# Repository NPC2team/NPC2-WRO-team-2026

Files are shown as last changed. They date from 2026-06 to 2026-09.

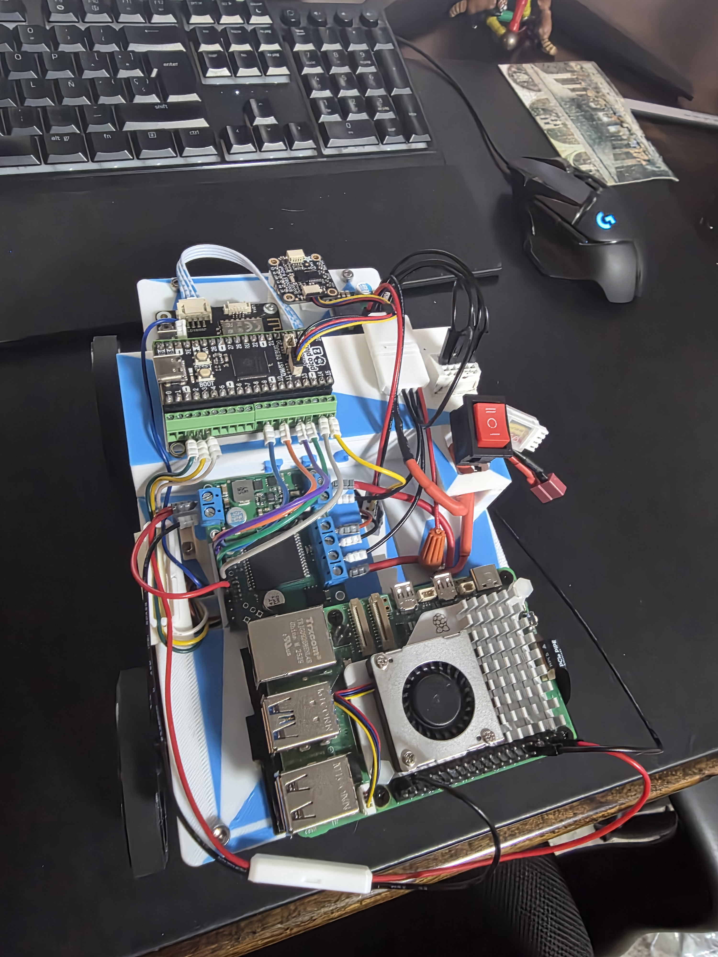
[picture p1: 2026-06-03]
setup of the car and software/Carro desde Arriba Listo.jpg

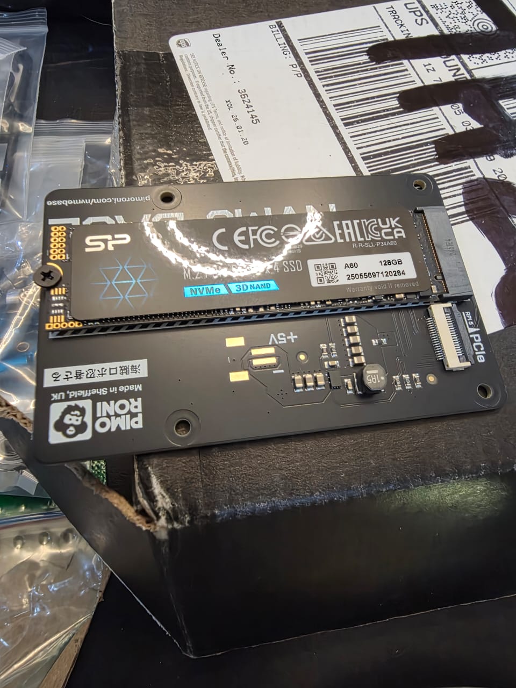
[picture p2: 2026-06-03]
setup of the car and software/Base NVME.jpeg

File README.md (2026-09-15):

## **NPC – WRO FUTUROS INGENIEROS 2026** 

## **CONTENIDO** 
## **1. Introducción e Información del Equipo**
- a. Introducción 
- b. Miembros del Equipo 
## **2. Vehículo** 
- a. Descripción del Vehículo 
- b. Fotos del Vehículo 
## **3. Videos de Pruebas del Vehículo** 
- a. Reto 1 – Open Challenge 
- b. Reto 2 – Obstacle Challenge 
## **4. Movilidad y Diseño Mecánico (Criterio 1)** 
- a. Chasis 
- b. Sistema de Tracción 
- c. Sistema de Dirección 
## **5. Arquitectura de Potencia y Sensores (Criterio 2)** 
- a. Sistema de Potencia 
- b. Power Budget 
- c. Sensores 
- d. Diagrama de Comunicación 
- e. Ubicación de Sensores 
- f. Diagrama de Cableado 
- g. Decisión de Diseño
## **6. Arquitectura de Software y Estrategia de Obstáculos  (Criterio 3)** 
- a. Visión General
- b  Estructura del Código
- c. Tópicos 
- d. Firmware del Pico 2 
- e. Estrategia del Reto Abierto
- f. Diagrama de Flujo de Reto Abierto
- g. Métricas de Desempeño del Reto Abierto 
- h. Nodos y Tópicos de Reto con Obstáculos
- i. Estrategia del Reto con Obstáculos
- j. Detección de Pilares R/G/M (cámara)
- k. Diagrama de Flujo de Reto con Obstáculo
- l. Métricas de Desempeño del Reto con Obstáculos
- m. Ajustes Realizados en Ambos Retos
## **7. Pensamiento Sistémico y Decisiones de Ingeniería (Criterio 4)** 
 - a. Diagrama de Bloques del Sistema
 - b. Interacción entre Subsistemas
 - c. Restricciones (Constraints) Identificadas
 - d. Decisiones de Diseño Principales
 - e. Análisis de Riesgos y Mitigación
 - f. Historial de Iteraciones (resumen)
## **8. Instrucciones de Reproducibilidad (Criterio 5)** 
 - a. Requisitos de Hardware
 - b. Requisitos de Software
 - c. Instalación Paso a Paso
 - d. Estructura del Repositorio
 - e. Cómo Arrancar el Sistema
 - f. Notas de Ensamblaje
 - g. Journal Detallado
<br>
<br>

## **1. Encabezado e Información del Equipo** 

## 1a. Introducción 
<div>
Equipo<br>
   
Somos el equipo **NPC (Non Playable Character)**, este es nuestro segundo año en competencias de la WRO, con el objetivo de lograr un vehículo verdaderamente autónomo que supere con éxito los retos de la competencia WRO Futuros Ingenieros 2026 a Nivel Nacional y nos permita obtener nuestro cupo en la Final Internacional de Puerto Rico. 

Vu Tue Anh, compitió el año pasado en la categoría de Misiones Roboticas, mientras que Leonardo y Juan participaron en la categoría de Futuros Ingenieros, llegando a la Final Nacional de Venezuela donde obtuvimos el 5to Lugar, mientras que en un invitacional en Weifang, China logramos el 1er Lugar. 
</div>
<br clear="left" />

## 1b. Miembros del Equipo 

## **Juan Ignacio Gonzalez** 

foto de juan<br>
Hola soy Juan, soy venezolano/español y tengo 16 años, actualmente estudio 4to año de bachillerato y miembro del Club de Robótica del Colegio Jefferson.  Este es mi segundo año en la competencia de la WRO de Futuros Ingenieros. En 2025, junto con Leonardo obtuvimos el 5to Lugar en la Final Nacional y el 1er Lugar en un invitacional en Weifang, China. 

Mis aportes al equipo se han enfocado en el código de Arduino IDE/Python, así como la realización de pruebas de los distintos componentes y de los retos. 

<br clear="left" />

## **Leonardo Carrasquero** 

Foto Leo<br>
Hola soy Leo, venezolano/italiano de 16 años, estudio 4to año de bachillerato y soy miembro del Club de Robótica del Colegio Jefferson 2024.  Al igual que Juan, este es mi segundo año en la categoría de Futuros Ingenieros y este año quiero lograr participar en la Final Internacional de Puerto Rico. 

Mis contribuciones se enfocaron en la investigación de componentes, diseño e impresión de piezas 3D, ensamblaje del robot, así como programación en Python y ROS2. 

<br clear="left" />

## **Vu Tue Anh** 

Foto Vu<br>
Hola soy Vu, de origen vietnamita y llevó 3 años viviendo en Venezuela y soy compañera de 4to año de Juan y Leonardo, en el Colegio Jefferson. Este también es mi segundo año en competencias de la WRO, pero el año pasado estuve en la categoría de misiones roboticas. Este año quise cambiar y tener el reto de participar en Futuros Ingenieros. 

Para nuestro proyecto, fui responsable en la realización de pruebas, así como de la documentación y registro fotográfico. 

<br clear="left" />

## **Alfredo Gonzalez**

<br>
Alfredo, es nuestro coach y de profesion matemático. 

Él también es nuestro profesor de robótica en el Colegio Jefferson y ha estado desde 2023 participando en competencias de la WRO en Venezuela, dirigiendo a varios equipos del colegio en las distintas categorias, con participaciones en las Regionales, Final en Venezuela, Final Internacional y diversos invitacionales.

<br clear="left" />

## **Foto del Equipo Junto y Foto en China** 

Foto Equipo China

3DC51F0D-4A7F-49F5-A332-7C0CE98BB8BD

## **2.Robot** 

## 2a. Descripción del Robot 

**“Proyecto Mahoraga”** es nuestro vehículo para Futuros Ingenieros 2026, bautizado en alusión al poderoso personaje del Anime Jujutsu Kaisen por su capacidad de adaptación.

**“Proyecto Mahoraga”** representa una evolución significativa con respecto a **“Crazy Diamond” (WRO 2025)**, con quien ya logramos triunfos y a quien le agradecemos el aprendizaje. Proyecto Mahoraga presenta mejoras en hardware, diseño y software que nos permitirá ejecutar con éxito los retos de Futuros Ingenieros 2026. Abordaremos con detalle en este Readme las características del Robot, el proceso de diseño, construcción y programación, así como las decisiones y obstáculos que tuvimos en el camino, con la finalidad de que sea posible replicar por cualquier entusiasta de la robótica como nosotros. En la carpeta ***Selección de Componentes y Comparación con 2025*** se podrá ver el detalle de la mejora vs Crazy Diamond (2025) y porque se seleccionó cada componente, mientras que en la carpeta de ***Journal*** detallaremos el diario con los avances semana a semana de la labor para construir **“Proyecto Mahoraga”**.

## 2b. Fotos del Robot 

<table>
  <tr>
    <td align="center">
      <b>Vista Frontal</b><br>
       22 Frontal
    </td>
    <td align="center">
      <b>Vista Trasera</b><br>
      
    </td>
    <td align="center">
      <b>Lado Izquierdo</b><br>
      19 Foto Izq
    </td>
  </tr>
  <tr>
    <td align="center">
      <b>Lado Derecho</b><br>
      20 Foto Derecha
    </td>
  <td align="center">
  <b>Vista de Arriba</b><br>
 18 Foto de Arriba
</td>
    <td align="center">
      <b>Vista de Abajo</b><br>
      
    </td>
  </tr>
</table>

## **3. Videos de Pruebas del Vehículo** 

3a. Reto 1 – Open Challenge 

**Link YouTube** 
(https://youtube.com/shorts/lqm2GCjuBmU?feature=share)

3b. Reto 1 - Open Challenge con la caja grande en todos los lados

**Link Youtube**
(https://youtu.be/qX_5btinKA8)

3c. Reto 1 - Open Challenge con un lado de la caja más grande que el otro.

**Link Youtube**
(https://youtube.com/shorts/0UPQsAmQOhI)

3d. Reto 2 intento– Obstacle Challenge 

**Link YouTube** 
(https://youtu.be/Lv-a8dN4dbw)
## **4. Movilidad y Diseño Mecánico (Criterio 1)** 

En este apartado documentamos la ficha técnica de la configuración mecánica final de **Proyecto  Mahoraga**,  los ajustes realizados sobre la versión inicial de Proyecto Mahoraga y los cálculos detallados del Ackerman, torque y velocidad. En  ***Selección de Componentes y Comparación con 2025***,  mostramos las  mejoras sobre nuestro robot Proyecyo Mahoraga respecto a Crazy Diamond 2025.

## 4a. Chasis 

Originalmente pensamos que necesitaríamos 3 pisos para alojar todos los componentes y en un ancho relativamente angosto. Al avanzar el diseño nos dimos cuenta de que esto generaba: 
· Centro de masa elevado, perjudicial en curvas cerradas
· Peso adicional innecesario por la estructura extra
· Mayor altura total del robot

Finalmente pensamos que era mejor 2 niveles, con un subnivel adicional y un compartimiento hecho a la medida para la batería Lipo S3 11.1V. Esto con la finalidad de hacer más eficiente el uso del espacio y lograr obtener un robot más pequeño y ágil. Las piezas fueron impresas en 3D, dándonos mayor flexibilidad en el diseño y permitiéndonos adecuar los espacios a los componentes mecánicos y eléctricos de Proyecto Mahoraga. 

Chasis Comentado

|**Atributo**|**Descripción**|
|---|---|
|Tipo|Personalizado, diseñado en Fusion|
|Material|PLA impreso en 3D(Bambu Lab P2S)|
|Dimensiones|234 × 135 × 126 mm|
|Distribución vertical|2 pisos modulares + 2 subniveles|
|Distancia entre ejes(batalla)|142 mm|
|Distancia entrepivotes|97 mm|
|Peso(sin cámara)|1.100g (límite reglamentario: 1500g)|

### Evolutivo del Chasis

Las piezas fueron diseñadas en Fusion e impresas en 3D, utilizando una Impresora Bambu Lab P2S con Filamento PLA. El infill general utilizado fue 15% por default, excepto en el chasis que se ajustó en las últimas versiones a 55% para mayor fortaleza y algunas otras piezas que requirieron un poco mas de Infill (30%).

|**Pieza**|**Prototipo**|**Versión_#1**|**Versión_#2**|**Versión_Final**|**Foto_Real**|**Comentarios**|
|---|---|---|---|---|---|---|
|Chasis de Abajo|Chasis Abajo Prototipo|Chasis Abajo V1|Chasis Abajo V2|Chasis Abajo VF|Chasis Abajo Foto|El Chasis de Abajo ha tenido varias evoluciones, desde un Prototipo en cartón que hicimos para ver si se ajustaban las piezas. La Versión 1 incluye un agujero para colocar la transmisión, así como el espacio necesario adelante para colocar el LiDAR. La Versión 2 mas refinada, incluye algunos agujeros para tornillos del soporte del Chasis de Arriba, las C Hub incorporadas para la Dirección. La Versión Final ademas de incorporar mas agujeros para los tornillos de los soportes, también incrementa el espacio para el LiDAR y asi lograr un FOV libre de 180 grados y esta impreso con un Infill de 55% para lograr mayor consistencia y se fortalecieron los C Hub, que comenzaron a doblarse en la versión anterior. 
|Chasis de Arriba|Chasis Arriba Prototipo|Chasis Arriba V1| Chasis Arriba V2|Chasis Arriba VF|Chasis Arriba Foto|El Chasis de Arriba comenzamos con un Prototipo en cartón vara visualizar los componentes a comprar tenian el espacio requerido. La Versión 1 incluye el habitáculo de la batería entre ambos niveles, pero una Versión 2 refinó espacio para los cables, soporte para el suitche de encendido y orificios para los soportes que unen ambos chasis. La Versión Final, refina la colocación del suiche y se crea un subnivel para elevar un poco el RPI 5 y el subnivel encima de la batería para comodar mejor otros compotentes. Finalmente un espacio frontal adicional para centrar bien la cámará, justo encima del LiDAR|

|**Pieza**|**Modelo Fusion**|**Versión_#1**|**Versión_Final**|**Foto_Real**|**Comentarios**|
|---|---|---|---|---|---|
|Sujeta Cables|Sujeta Cable Prototipo en Fusion|No Aplica|Sujeta Cables VF|Sujeta Cables Foto|Sujeta cable Dupont, útil para asegurar que los cables dupont conectados al Servo no se sueltes, igual lo usamos para canalizar cables dupont a través del chasis| 
|Soporte de Rolineras|Soporte de Rolinera Prototipo en Fusion|No Aplica|Soporte de Rolinera Tapa VFinalSoporte de Rolinera VFinal|Soporte de Rolinera Foto|Diseñadas para suetar rolinera que soporta el tren trasero del diferencial. El diseño original llevaba 2 (una de cada lado), pero luego del la Regional 1 de Miranda se decidió incluir 2 adicionales para dar mayor soporte.| 

Todos los archivos en STL/3MF están en **/models** (chasis de abajo y de arriba, soportes de motor y servo, carcasa y engranajes del diferencial y motor, espaciadores, repisa, canales de cables con tapas). 

***En la carpeta "Selección de Componentes y Comparación con 2025" puede verse el detalle de la mejora vs Crazy Diamond (2025) para estos componentes, culminando con un robot 300 grms mas ligero, 5 cms mas corto y 4 cms menos ancho***

## 4b. Sistema de Tracción 

Traccion4

- Elegimos un motor Pololu 34:1 Metal Gearmotor 25Dx67L mm MP 12V con Encoder 48 CPR por su alta calidad y más que velocidad buscábamos precisión y torque, por lo que al incluir el diferencial nos generó 2.006 ticks por metro medidos por el encoder, permitiéndonos un control más fino, tanto para la medición de las distancias recorridas como para las maniobras del estacionamiento. 

 - Reutilizamos el diferencial utilizado por Crazy Diamond en 2025, ajustándolo al menor ancho de Proyecto Mahoraga e imprimimos un nuevo engranaje para el motor porque el eje era de menor diámetro y necesitaba otro flange para ajustar correctamente. 

 - El motor es manejado por un Pololu VNH5019 de alta estabilidad, con buen manejo de energía que lo protege de cambios bruscos de dirección y le permite mantener la precisión al robot. El motor se fijó al chasis a través de un soporte hecho a la medida en impresión 3D, para garantizar la altura ideal para engranar con la barra del diferencial y lograr la sujeción para evitar movimientos producto de la vibración. El soporto requirió de varias iteraciones en el diseño, hasta la última que incluyó pestañas para fijarlo al chasis con tornillos de precisión.

 - Incorporamos unas ruedas de 11mm de ancho de aluminio con neumático de goma, menos anchas que el estándar de 25mm, lo cual nos permite reducir el ancho, disminuir la fricción y mejora la estabilidad efectiva pese, al menor ancho su mayor peso permite bajar el centro de gravedad del motor.

<br clear="left" />

|**Atributo**|**Descripción / Valor**|
|---|---|
|Tipo|Tracción trasera (RWD)|
|Motor|Pololu 34:1 Metal Gearmotor 25Dx67L mm MP 12V|
|Velocidad Lineal|1,1231 m/s|
|Encoder|48 CPR en el eje del motor|
|Torque|1,65 Kg/cm(Sin Diferencial) 2,32 Kg/cm(Con Diferencial)|
|Resolución calibrada|2.006 ticks/metro(medido enpruebas)|
|Driver del Motor|Pololu VNH5019 Tecnología MOSFET|
|Diferencial|Impreso 3D propio (Gear Diferencial + Gear Box)|
|Eje trasero|KYX Racing acero (Tamiya DT04)|
|Ruedas|64 mm aluminio, ancho 11 mm + neumático de goma|

### Encoder 
El Encoder conectado al motor de fabrica trae una calibración para al ser conectado al diferencial necesitamos recalcularlo.

Encoder calibrado empíricamente <br>
A pesar de que en teoría la resolución del encoder es: <br>
```bash
48 Counts per Revolution (CPR) × 34 Relación del Motor = 1.632 CPR en la rueda
```
Para saber cuánto avanza el robot en una vuelta, calculamos el perímetro de la rueda con la siguiente fórmula:
```bash
Circunferencia =  π x Diámetro de la rueda = 3,1416 x 0,065 metros = 0,2042 metros
Una vez que tienes el perímetro (en metros), divides los pulsos de una vuelta entre esa distancia:
Ticks por metro = CPR en la rueda (1.632) / Circunferencia de la rueda en metros (0,2042 metros) = 7.992 ticks por metro
```
```bash
En la práctica intervienen el diferencial impreso, la elasticidad del neumático de goma y los acoples mecánicos que hacen
una relación cercana a una reducción 4:1, por lo que la medición en pruebas nos dio:
2.006 ticks / metro
```
Esta calibración empírica es un ejemplo de iteración basada en datos: en lugar de confiar en el cálculo teórico, ejecutamos ensayos repetibles desplazando el robot distancias conocidas y contando ticks acumulados.

### Cálculo de velocidad lineal teórica 
```bash
Circunferencia =  π x Diámetro de la rueda = 3,1416 x 0,065 metros = 0,2042 metros
Velocidad = (RPM / 60) × Circunferencia = (330 / 60) × 0,2042 metros
Velocidad ≈ 1.1231 m/s
```
***A esta velocidad con un perímetro estimado de 10 metros por vuelta, nos da una vuelta en 8,9 segundos, un tiempo total necesario para 3 vueltas de 27 segundos. Esto deja margen amplio dentro del tiempo límite reglamentario y es un tiempo bastante competitivo versus lo conseguido por otros equipos en años anteriores.*** <br>

### Cálculo del Torque del Motor

El Pololu 34:1 Metal Gearmotor 25Dx67L mm MP 12V tiene un Torque según sus características de 0,065 Kg.cm y una eficiencia entre 70% y 80%. <br>
```bash
Torque de salida =  Torque del Motor x Relación del Motor x N (Eficiencia)
Torque de salida = 0,065 kg/cm x 34 x 0,75 = 1,65 kg/cm
```

Al considerar el diferencial, tenemos que incluir la relación del diferencial, que se calcula como la relación entre el número de dientes de la corona (18) dividido por el número de dientes del piñón del diferencial (12). <br>
```bash
Torque de salida =  Torque del Motor x Relación del Motor x N (Eficiencia) x Relación Diferencial
Torque de salida (con Diferencial) = 0,065 kg/cm x 34 x 0,75 x (18/12) = 2,32 kg/cm
```

***Este torque nos da la tranquilida de resistir sin problema el peso del robot y ademas garantizar la precisión en los movimientos***

### Evolutivo de Piezas de Tracción 

Los engranajes y la caja del diferencial fueron diseñados en Fusion e impresos en 3D utilizando una Impresora Bambu Lab P2S con Filamento PLA, excepto en el caso del engranaje del Motor que en su última versión necesitó un filamenento de Nylon (PA de Fibra de Carbono) mas resistente y que soporta mayores temperaturas, para corregir la falla presentada en el Regional de Miranda. El infill general utilizado fue de 30% y 50%.

|**Pieza**|**Modelo Fusion**|**Versión_#1**|**Versión_Final**|**Foto_Real**|**Comentarios**|
|---|---|---|---|---|---|
|Soporte Motor|Soporte Motor Prototipo en Fusion|Soporte de Motor V1|Soporte de Motor VF|Soporte Motor Foto|Un diseño inicial que no ajusto bien el motor y las vibraciones provocaban desplazamientos que movian el ajuste de los engranajes. La Versión Final ajustó esa falla y ademas se colocaron pestañas para tornillos dado que la sujeción por debajo de la V1 hacia complicado su posicionamiento exacto en el chasis|
|Gear Motor|Gear Motor Prototipo|Gear Motor V1|Gear Motor V Final| Gear Motor Foto| El engranaje del motor se tuvo que volver hacer luego de la Regional 1 de Miranda, porque el uso comió el hole del engranaje y quedó con poco agarre y hacía que al robot le costara arrancar. Se imprimió nuevamente en Nylon para mayor resistencia al calor de la fricción y al uso. El diseño original se hizo usando una herramienta de diseño de MarketWorld [https://makerworld.com/](https://makerworld.com/es/makerlab/parametricModelMaker](https://makerworld.com/es/makerlab/parametricModelMaker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))| 
|Gear Diferencial|Gear Diferencial Prototipo|No Aplica|Gear Diferencial VFinal|Gear Diferencial Foto|El diseño original se hizo usando una herramienta de diseño de MarketWorld [https://makerworld.com/](https://makerworld.com/es/makerlab/parametricModelMaker](https://makerworld.com/es/makerlab/parametricModelMaker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))| 
|Gear Caja de Diferencial|Gear Box Diferencial Prototipo Fusion|No Aplica|Gear Box Diferencial VFinal|Gear Box Diferencial Foto Final|El diseño original se hizo usando una herramienta de diseño de MarketWorld [https://makerworld.com/](https://makerworld.com/es/makerlab/parametricModelMaker](https://makerworld.com/es/makerlab/parametricModelMaker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))| 
|Espaciador Diferencial|Espaciador Diferencial Prototipo Fusion|No Aplica|Espaciador Diferencial Versión Final|Espaciador Diferencial Foto|Espaciador en el diferencial para ajustar la caja de engranajes del diferencial a los soportes de la rolineras y que el eje trasero y el diferencial no se muevan lateralmente| 

***En la carpeta "Selección de Componentes y Comparación con 2025" puede verse el detalle de la mejora vs Crazy Diamond (2025) para estos componentes, culminando con un robot con un controlador mucho mas eficiente, con ruedas mas angostas, pero firmes al ser de aluminio y motor con prestaciones comparables pero menor tamaño y peso***

## 4c. Sistema de Dirección 

Direccion

Uno de los principales retos de este año era que el vehículo debía ser más ágil, para lo cual había que reducir su tamaño y mejorar su capacidad de giro. Con batalla 142 mm y pivotes 97 mm, el robot recorre 34,2 cm para girar 90°, frente a los 48,2 cm del chasis 2025 (−29%). 

La transmisión del movimiento del servo a las ruedas usa componentes de calidad de radio control de competición:
- Servo Saver Tamiya TT-02 Hi-Torque: protege el servo absorbiendo impactos cuando el robot roza una pared o choca, así como un sobregiro imprevisto. 
- Manguetas KYX Racing aluminio (Tamiya DT04): soportan las ruedas delanteras con pivote Ackermann. Aluminio para resistencia bajo cargas laterales repetidas.
- Tie rods M3 ajustables (uxcell): rosca M3 que permite ajuste fino de longitud. Esto es crítico porque, con piezas fijas impresas, un error de 2 mm dejaría las ruedas "bizcas" (chuecas).
- Ejes de acero inoxidable 5 mm × 100 mm (uxcell): pivote rígido sin flexión.
- Los C Hub o portamanguetas de dirección fueron integrados en el chasis de abajo, permitiendo el mayor cruce que podía aportar el servo. El servo Savox SC-1251MG aporta precisión de ángulo de giro al ser digital, tener engranajes metálicos y ser coreless, permitiéndole además una alta velocidad de respuesta 0.09s/60°. 

A diferencia de 2025, colocamos el servo detrás de las ruedas delanteras. Esta decisión liberó el espacio frontal para colocar el LiDAR en posición baja y adelantada. 

El servo está fijado al chasis a través de un soporte hecho a la medida en impresión 3D, para garantizar la altura ideal de las barras conectadas a las manguetas. El soporto requirió de varias iteraciones en el diseño, hasta la última que incluyó pestañas para fijarlo al chasis con tornillos de precisión.

<br clear="left" />
<br>

|**Atributo**|**Descripción / Valor**|
|---|---|
|Geometría|Ackermann|
|Servo|Savox SC-1251MG (digital, coreless,<br>engranajes metálicos)|
|Par servo|9.0 kg·cm@6.0 V|
|Velocidad servo|0.07 s/60°|
|Posición del servo|Detrás de las ruedas delanteras|
|Servo saver|Tamiya TT-02 Hi-Torque|
|Manguetas|KYX Racingaluminio(Tamiya DT04)|
|Tie rods|M3 ajustables(uxcell)|
|Ángulo degiro máximo|50°|
|Batalla(L)|142 mm|
|Pivotes(W)|97 mm|
|Radio degiro(R)|217,7 mm a 40°|
|Distancia para 90°|341,90 mm|

### Sistema de Dirección Ackerman

Competir en Future Engineers WRO 2026 requiere un vehículo de 4 ruedas con dirección real (no diferencial). En el sistema Ackermann la rueda delantera interior gira a un ángulo mayor que la rueda exterior, dado que si las dos ruedas delanteras giraran al mismo ángulo (paralelas), la rueda interna (la del lado interior de la curva) se vería forzada a "arrastrar" o derrapar. 

Para aplicar la geometría Ackermann no usamos las dimensiones externas del chasis, sino las de los puntos de giro reales. La distancia entre pivotes es menor que el ancho total porque las ruedas tienen grosor y los tornillos sobre los que giran (pivotes) están dentro del contorno de las ruedas.

***Fórmula del radio de giro***

La fórmula completa que considera tanto la batalla como la distancia entre pivotes en un giro a 40 grados es:

```bash
R  = L / tan(δ) + W / 2
R = 142 / tan (40°) + 97 / 2
R = 142 / 0,839 + 48,5 
R = 217,7 mm
```

***Cálculo de la distancia recorrida en un giro de 90°***

```bash
Distancia = (2 × π × R) / 4
Distancia = (2 × π × 217,7) / 4 ≈ 341,9 mm
```

***Bajo este calculo y probado en la practica, Proyecto Mahoraga es capaz de hacer un giro de 90 grados en 34,2 cms.***

### Evolutivo de Piezas 3D de Dirección 

El soporte del servo hecho a la medida y altura necesaria, asi como los C-Hubs fueron diseñados en Fusion e impresos en 3D utilizando una Impresora Bambu Lab P2S con Filamento PLA. El infill general utilizado fue de 15% para el soporte y 30% para el C-Hubs aunque este último se descartó en el diseño final por incluirse en la placa del chasis.

|**Pieza**|**Modelo Fusion**|**Versión_#1**|**Versión_Final**|**Foto_Real**|**Comentarios**|
|---|---|---|---|---|---|
|Soporte Servo|Soporte Servo Prototipo en Fusion|Soporte de Servo V1|Soporte de Servo V2| Soporte Servo Foto|El diseño inicial tenía su atornillado por debajo y dificultaba su ajuste al chasis, ademas los agujeros a los tornillos quedaron muy flojos por usar un infill muy bajo en la pieza (15%). La Versión Final ajustó esa falla con un Infill de 30% y ademas se colocaron pestañas para tornillos para mas fácil ajuste al chasis |
|C Hubs|C Hubs V1|No Aplica|Descartada, al incluirse en el Chasis en la Versión V1 en adelante|C Hubs Foto|Ideada para sostener las manguetas de la dirección en vez de comprar unas comerciales. sin embargo se incluyeron en el diseño del Chasis V1| 

***En la carpeta "Selección de Componentes y Comparación con 2025" puede verse el detalle de la mejora vs Crazy Diamond (2025) para estos componentes, culminando con un robot con un una capacidad de giro mayor en 29% gracias a su menor tamaño que disminuyo tanto su Batalla como Pivotes. Ademas el servo digital añade precisión y velocidad de respuesta.***

## **5. Arquitectura de Potencia y Sensores (Criterio 2)** 

En este apartado documentamos la ficha técnica del sistema de alimentación, distribución de potencia, power budget, autonomía de batería y arquitectura de sensores para **Proyecto Mahoraga**. 

## 5a. Sistema de Potencia 

|**Componente**|**Modelo**|**Especificaciones**|
|---|---|---|
|Batería|Zeee LiPo 3S|11.1 V nominal (12,6 V plenamente cargada), 3.000 mAh, 50C, conector T|
|Regulador Principal<br>(lógica)|Pololu D24V90F5|5V salida, 9 A continuos|
|Regulador  Servo|Pololu D36V50F5|5V salida, 5,5 A continuos|
|Motor Driver|Pololu VNH5019|Rango Operativo 5,5 a 24V, Cpacidad 12 A|

La bateria 3S nos permite alimentar correctamente el motor Pololu 34:1 25Dx67L MP 12V y sacar provecho de su potencia. 

**Decisión clave:** Distribución dual de reguladores 5V. El D24V90F5 (9A) alimenta toda la lógica del robot (Raspberry Pi 5, Pico Plus 2, LiDAR, IMU, TOF, lógica del VNH5019). El D36V50F5 (5.5A) alimenta exclusivamente el servo Savox SC-1251MG, que tiene picos de corriente de hasta 3,5A durante giros bruscos o choques. Esto aísla los transitorios del servo del riel de lógica sensible, evitando reinicios del Raspberry Pi 5 o del Pico Plus 2 o errores en los datos de los sensores.

Distribucion de Potencia

## 5b. Power Budget 

Como se observa en la tabla del Power Budget, el uso de los 2 reguladores nos da holgura y mitiga el riesgo en picos de voltaje. 

**Capacidad regulador lógica (9 A) y servo (5.5 A), ambos con margen de seguridad ≥50% respecto al consumo pico estimado.**

|**Componente**|**Voltaje**|**Corriente**<br>**típica**|**Corriente**<br>**pico**|**Notas**|
|---|---|---|---|---|
|Raspberry Pi 5 (16GB) +<br>NVMe|5 V|1,5 A|3,0 A|Fuente oficial recomienda 5A|
|Active Cooler RPi 5|5 V|0.05 A|0.1 A|Ventilador PWM|
|SSD M.2 NVMe Silicon<br>Power|3,3 V|0,3 A|0,5 A|Alimentado vía NVMe Base|
|Pico Plus 2 (RP2350)|5 V|0,05 A|0,15 A|Alimentado desde RPi vía USB|
|Terminal PiCowbell|5 V|<0,01 A|<0,01 A|Solo terminales / reset|
|LiDAR STL-27L|5 V|0,3 A|0,3 A|21.600 mediciones/s, 10Hz|
|IMU BNO085|3,3 V (Qwiic)|0,015 A|0.025 A|Bajo consumo|
|VL53L4CD ToF ×2|3,3 V (Qwiic)|0,020 A c/u|0,05 A c/u|Sensor láser pulsado|
|Cámara Global Shutter|3,3 V (FPC)|0.25 A|0,4 A|Alimentada por RPi|
|SparkFun Qwiic<br>MultiPort|3,3 V|<0,001 A|<0,001 A|Pasivo|
|Servo Savox<br>SC-1251MG|5 V|0,5 A|3,5 A (stall)|Posibilidad de picos en giros y<br>choques|
|Motor Pololu 34:1 12V|11,1 V (LiPo)|0,5 A|5,0 A (stall)|Alimentación directa|
|Encoder magnético|3,3 V|0,01 A|0,015 A|Alimentado por Pico 2|
|VNH5019 (lógica)|5 V|<0,01 A|<0,01 A|Solo lógica; potencia va por LiPo|
|**TOTAL bus lógica (5V**<br>**vía D24V90F5)**<br>**TOTAL bus servo (5V**<br>**via D36V50F5)**<br>**Bus 11,1V MOTOR**<br>**(directo)**||**~2,2 A**<br>**~0,5 A**<br>**~0,5 A**|**~4,0 A**<br>**~3,5 A**<br>**~5,0 A**|Margen: +125 % pico, +309%<br>continuo<br>Margen: +57 % pico, +1.000%<br>continuo<br>Margen: +140 % pico|
|**TOTAL desde LiPo 3S**||**~3,2 A**|**~9,0 A pico**||

### Cálculo de Autonomía de Batería

***Consumo***
```bash
El bus de la lógica D24V90F5 de 5V consume 2.2 A
2,2 A x 5V = 11.000 mA 
El bus del servo D36V50F5 de 5V consume 0.5 A
0,5 A x 5V = 2.500 mA 
El bus del Motor de 11,1v via VNH5019 consume 0.5 A
0,5 A x 11,1V = 5.550 mA 

Total de Consumo 18.000 mA

Los reguladores buck Pololu D36V50F5 y D24V90F5) son ~90% eficientes. 

Entonces la batería tiene una razon de 11,1V x 90% = 9,99

Reexpresando el Consumo tenemos C = 18,000 / 9,99 = 1801,8 mA @ 11.1V
```
***Batería***
```bash
La	bateria Lipo 3S es de 11.1V y con capacidad de 3.000 mAh
Considerando una Capacidad Útil de 70%, dado que en la práctica la batería a full carga arranca con un voltaje de 12,5V, tendíamos:
Capacidad Útil = 3.000 mAh x 70% = 2.100 mAh

Autonomia = Capacidad de Bateria (mAh) / Consumo Total (mA)
Autonomia = 2.100 mAh / 1.802 (mA)
Autonomia = 1,1655 h = 69,9 minutos
```

En la práctica hemos visto autonomía similares, pero hemos establecido un cambio de bateria mas conservador cercano a los 50 minutos de uso, que normalmente han sido unas 10 pruebas de 3 giros, mas el tiempo que ha estado prendido el robot en modo de debugging o de ajuste de algunas variables del código. 

## 5c. Sensores 

Uno de los upgrades más importantes que hicimos en **Proyecto Mahoraga** fue tener sensores de alto nivel. El LiDAR era una adición necesaria para el manejo de los obstáculos de una manera robusta. La ubicación y control preciso de los movimientos del robot queda cubierta con el IMU BNO085 y el Encoder. La cámara es un upgrade más profesional vs la Pixy que utilizamos en 2025 y los TOF VL53L4CD son un nivel más sofisticado que los ultrasónicos HC-SR04. 

|**Sensor**|**Modelo**|**Función**|
|---|---|---|
|LiDAR STL-27L |LiDAR 360° <br> LDROBOT STL-27L|Con 21.600 mediciones por segundo a 10 Hz (10<br>vueltas de 2.160 mediciones) es muy útil para la<br>detección de paredes y obstáculos.|
|IMU|IMU 9-DOF <br> Adafruit BNO085|Entrega orientación absoluta directamente como<br>quaternion, permitiendo una fácil orientación<br>absoluta.|
|TOF|ToF láser <br> Adafruit<br>VL53L4CD|Prácticamente sin punto ciego, distancia lateral<br>izq/der (1–1300 mm) a 100 Hz, es muy útil para<br>tareas de precisión como estacionar.|
|CamaraGS |Cámara Raspberry Pi <br> Global Shutter<br>|Visión por computador para detectar pilares<br>rojos/verdes. Al ser Global Shutter limita las<br>distorsión de objetos en movimiento.|
|GS Lens|Lente CCTV M12 <br>2.8mm F2.0|Campo de visión amplio para captura 96°>|
|Encoder|Magnetic Encoder<br>Pololu|48 CPR motor, 2.006 ticks/m calibrados|

***En la carpeta "Selección de Componentes y Comparación con 2025" puede verse el detalle de la mejora vs Crazy Diamond (2025) y porque se seleccionaron estos componentes, culminando con un robot con un una capacidad muy superior por el uso del LiDAR para mapear obstaculos y paredes, y en el reposa buena parte de la responsabilidad de navegación como veremos mas adelante.***

### Evolutivo de Piezas 3D para Sensores 

Se construyó una repisa especial para alojar el IMU BNO085 que debía estar cerca del Pico Plus 2, tambien se construyó un sencillo pero eficaz soporte de camara para que se atornillara al chasis en un angulo ideal. Las piezas fueron diseñadas en Fusion e impresos en 3D utilizando una Impresora Bambu Lab P2S con Filamento PLA. El infill utilizado fue de 30%.

|**Pieza**|**Modelo Fusion**|**Versión_#1**|**Versión_Final**|**Foto_Real**|**Comentarios**|
|---|---|---|---|---|---|
|Repisa|Repisa Prototipo en Fusion|Repisa V1|Descartada, al incluirse en el Chasis en la Versión Final|Repisa|La Repisa se realizó para colocar la protoboard que lleva el IMU y el botón de inicio, iba atornillada al habitáculo de la batería| 
|Soporte Cámara|Soporte Camara Fusion|Soporte Camara V1| Soporte Camara VF|Soporte Camara GS Fotojpeg|Soporte para la Camara en su 1era versión fue para la Raspberry Cam Wide V3, como esa se nos dañó y empezamos a utilizar una Global Shutter, se realizó un nuevo soporte de cámara que consiste de una forma de tornilo para sostenerla desde abajo como un tripode, en un angulo de 60 grados.| 

## 5d. Topología de Comunicaciones 

Se caracteriza por una topología híbrida en estrella de alto rendimiento, donde la Raspberry Pi 5 actúa como el nodo central de procesamiento, conectada punto a punto mediante interfaces dedicadas a la cámara Global Shutter (vía MIPI CSI-2), al LiDAR STL27L (vía un puente USB-UART) y a una co-procesadora Raspberry Pico Plus 2 (vía USB-CDC). A su vez, la Pico Plus 2 funciona como un nodo secundario de control en tiempo real, gestionando un bus I2C/Qwicc compartido en paralelo para los sensores críticos de navegación (2 sensores de distancia TOF VL53L4CD y la IMU BNO085) y utilizando líneas independientes GPIO/PWM para el control directo de actuadores y hardware de movimiento, que incluyen un encoder, el driver de motor VNH5019 y un servo Savox SC-1251MG. 

Topologia de Comunicación2

#### Nodo central: Raspberry Pi 5

La Raspberry Pi 5 actúa como el nodo central de la estrella principal. Ejecuta Ubuntu 24.04 con ROS 2 Jazzy, y concentra todas las tareas que requieren capacidad computacional significativa: procesamiento del LiDAR (~2400 puntos por scan a 10 Hz), procesamiento de imagen de la cámara para el Reto de Obstáculos, ejecución del algoritmo de control a 40 Hz, y gestión de la máquina de estados de alto nivel. Se conecta punto a punto con tres periféricos a través de interfaces dedicadas, cada una elegida por sus características específicas de ancho de banda y latencia:

**Cámara RPi Global Shutter → Pi5 vía MIPI CSI-2:**
Interfaz nativa de la Raspberry Pi para cámaras, con ancho de banda de hasta 6 Gbps. Se eligió MIPI CSI-2 sobre USB porque elimina la sobrecarga del protocolo USB, ofrece menor latencia (crítica para procesamiento de visión en tiempo real) y libera los puertos USB para los demás dispositivos. La cámara Global Shutter fue seleccionada sobre una Rolling Shutter para evitar distorsiones tipo "jelly effect" durante el movimiento del robot.

**LiDAR STL-27L → Pi5 vía USB (con conversor USB-UART interno):**
El LiDAR se comunica internamente por UART a 921600 baudios, pero LDROBOT provee un cable con conversor CP2102N integrado que expone el dispositivo como puerto serial USB (/dev/ttyUSB0). 

**Pico Plus 2 → Pi5 vía USB-CDC:**
La comunicación con el microcontrolador utiliza el modo CDC (Communications Device Class) nativo del RP2350, que expone el Pico como puerto serial 
virtual (/dev/ttyACM0) a 921600 baudios. Se implementó un protocolo CSV liviano sobre esta conexión, con mensajes delimitados por saltos de línea. La elección de USB-CDC sobre alternativas como I2C o SPI se 
justifica por simplicidad y seguridad de conexión y el ancho de banda es más que suficiente para los 600 bytes/s del protocolo (posición, IMU, encoder, botón).

#### Nodo secundario: Pico Plus 2 (RP2350)

La Pico Plus 2 actúa como nodo secundario de control en tiempo real. Se eligió el RP2350 por su doble núcleo Cortex-M33 a 150 MHz, que 
permite dividir tareas críticas entre cores (odometría en Core 0, comunicación en Core 1) sin bloqueos. Gestiona a su vez una segunda estrella con dos tipos de buses según la naturaleza de cada periférico:

**Bus I2C (Qwiic) compartido para sensores digitales:**
Los sensores de navegación con salida digital comparten un único bus 
I2C0 en los GPIO 4 (SDA) y GPIO 5 (SCL), operando a 400 kHz. Este bus 
soporta:

- **IMU Adafruit BNO085** (dirección 0x4A): sensor de fusión 9-DOF que 
  provee cuaterniones estabilizados a 100 Hz. Se prefiere sobre IMUs 
  crudos porque la fusión sensorial está implementada en hardware 
  dedicado, liberando al microcontrolador de esa carga computacional.

- **2× VL53L4CD ToF** (reservados para el Reto de Obstáculos): sensores 
  de tiempo de vuelo para la maniobra de estacionamiento. Comparten el 
  mismo bus mediante gestión de direcciones I2C dinámica.

El bus I2C se eligió sobre conexiones GPIO individuales porque permite 
sumar sensores adicionales sin agotar los pines del microcontrolador, y 
sobre SPI porque los sensores utilizados solo ofrecen interfaz I2C 
nativa. El conector estándar Qwiic simplifica el cableado y evita 
errores de conexión.

**Líneas GPIO/PWM dedicadas para actuadores y sensores críticos de tiempo:**
Los dispositivos que requieren respuesta inmediata o generación precisa 
de señal utilizan pines dedicados, no un bus compartido:

- **Encoder del motor** (GPIO 2 canal A por interrupción, GPIO 3 canal B 
  por lectura digital): la lectura por interrupción por hardware 
  garantiza que no se pierdan pulsos incluso a máxima velocidad 
  (aproximadamente 4000 pulsos por segundo a velocidad de crucero).

- **Driver de motor Pololu VNH5019** (GPIO 8, 9, 10, 12, 13): 
  requiere 5 líneas independientes para dirección (INA, INB), 
  habilitación (ENA, ENB) y PWM a 20 kHz. El PWM se genera con hardware 
  para mantener la frecuencia por encima del rango audible.

- **Servo Savox SC-1251MG** (GPIO 15): requiere PWM preciso a 50 Hz con 
  pulsos entre 1.0 y 2.0 ms, generado con hardware dedicado del RP2350.

- **Botón de inicio** (GPIO 28, configurado como INPUT_PULLUP): 
  detección por interrupción para publicar el evento de inicio con 
  latencia mínima a la Pi5.

#### Racional de la elección de esta topología

La separación en dos niveles resuelve el procesamiento complejo que requiere un sistema 
operativo de propósito general (Linux) que no puede garantizar tiempos 
de respuesta determinísticos, mientras que el control de actuadores 
requiere precisión en el orden de microsegundos. Al delegar 
en la Pico las tareas de tiempo real (lectura de encoder, generación de 
PWM, integración de odometría), la RPi5 queda libre para procesamiento 
intensivo (LiDAR, visión, control) sin comprometer la seguridad del 
robot ante variaciones de latencia del sistema operativo.

## 5e. Ubicación de Sensores 

- **LiDAR:** primer piso, adelantado, altura óptima (FOV a 4,5 cms del piso) para detectar paredes y obstáculos de la pista (10 cm). 

- **Cámara:** segundo piso, inclinada 60 grados hacia abajo, captura el plano del suelo y los pilares con buena anticipación. 

- **IMU:** segundo piso, lo más alejado posible del motor y driver para minimizar EMI, pese a estar conectado por Qwiic, se fijó en una protoboard para garantizar no tuviera vibraciones. 

- **ToF #1 (izq) y ToF #2 (der):** apuntando perpendicular a las ruedas, retraídos 15 mm de la superficie exterior para eliminar la zona muerta del sensor. 

Ubicación de Sensores

<br>

## 5f. Diagrama de Cableado 

esquematico

**_Diagrama completo de conexiones eléctricas: ver schemes/esquematico detallado.png._** 
**_Detalle de cableado en cada componente: ver schemes/cableado detallado.pdf._** 

## **6. Arquitectura de Software y Estrategia de Obstáculos (Criterio 3)** 

## 6a. Visión General 

El software del robot **Proyecto Mahoraga** está construido sobre ROS 2 Jazzy corriendo en Ubuntu 24.04 en una Raspberry Pi 5, con un microcontrolador Pimoroni Pico Plus 2 (RP2350) encargándose de la lectura de sensores de bajo nivel y el control de actuadores. La arquitectura sigue un patrón distribuido de dos capas: 

• Raspberry Pi 5 (capa de alto nivel): ejecuta nodos ROS 2 para percepción, toma de decisiones y control a 40 Hz. 

• Pico Plus 2 (capa de bajo nivel): ejecuta un firmware basado en Arduino a mayor frecuencia para lectura del IMU, conteo del encoder, integración de odometría, generación de PWM del motor y del servo. 

La comunicación entre las dos capas ocurre por USB serial (921600 baudios) usando un protocolo CSV liviano, conectado a topicos ROS 2 mediante un nodo puente dedicado. 

Nodos y Topicos Reto 1

Elegimos ROS 2 como base porque su modelo de nodos comunicados por topics nos permitió descomponer el problema en piezas manejables: un nodo para el LiDAR, uno para el puente al microcontrolador, y uno para el control de alto 
nivel. Esta modularidad, junto con las herramientas de depuración que ofrece el ecosistema y la disponibilidad de drivers oficiales para nuestros sensores, fueron determinantes para completar el proyecto en 
el tiempo disponible. Las decisiones arquitectónicas específicas y sus trade-offs se detallan en la Sección 7.

## 6b.Estructura del Código

```
src/
├── firmware/
│   └── pico_firmware.ino          # Firmware C++ del Pico (Arduino)
├── npc_bot/                       # Paquete ROS 2 Python
│   ├── pico_bridge_node.py        # Puente USB ↔ topics ROS 2
│   ├── control_node.py            # Reto 1: Open Challenge
│   ├── control_node_reto2.py      # Reto 2: Obstacle Challenge
│   ├── nodo_camara.py             # Visión (solo Reto 2)
│   └── calibrador_hsv.py          # Calibración HSV interactiva
├── npc_interfaces/
│   └── msg/NpcPose.msg            # Mensaje custom {x,y,θ,acc_yaw}
├── launch/
│   ├── npc_bot.launch.py          # Lanza Reto 1 completo
│   └── base_reto2.launch.py       # Lanza Reto 2 completo
└── systemd/
    └── npc_bot.service            # Arranque Automatico Reto 1
    └── npc_bot_reto2.service      # Arranque Automatico Reto 2 
```

## 6c.Tópicos 

Se desarrolló un esquema de comunicación basado en tópicos, estableciendo los nodos suscriptores y publicador fundamental para la comunicación en ROS2.

|**Topic**|**Tipo**|**Publicador**|**Suscriptor**|**Descripción**|
|---|---|---|---|---|
|/scan|sensor_msgs/LaserScan|Driver LiDAR|control_node|Scan LiDAR 360° @10 Hz|
|/npcpos|npc_interfaces/NpcPose|pico_bridge|control_node|Pose del robot (x, y, theta,<br>acc_yaw) @50 Hz|
|/start|std_msgs/Empty|pico_bridge|control_node|Señal de inicio (botón)|
|/cmd_motor|std_msgs/Float32|control_node|pico_bridge|Velocidad del motor en m/s|
|/cmd_servo|std_msgs/Float32|control_node|pico_bridge|Dirección en [-1.0, +1.0]|
|/imu|sensor_msgs/Imu|pico_bridge|(debug)|Datos del IMU filtrados|
|/encoder|std_msgs/Int32|pico_bridge|(debug)|Ticks crudos del encoder|

## 6d. Firmware del Pico 2 

El Pico Plus 2 ejecuta un firmware basado en Arduino (un único archivo.ino) que maneja todas las operaciones de tiempo real de las que la RPi5 no debe encargarse. 

### **Responsabilidades** 

- Lectura del IMU a 100 Hz vía Qwiic I2C (Adafruit BNO085, con fusión sensorial 9-DOF onboard) 
- Conteo del encoder vía interrupción por hardware en GPIO 2 (Canal A) y lectura digital en GPIO 3 (Canal B), cuadratura de un solo flanco 
- Integración de odometría a 100 Hz (calcula Δx, Δy, Δtheta y los acumula) 
- Generación de PWM del motor a 20 kHz (sobre el rango audible) vía driver Pololu VNH5019 
- Generación de PWM del servo a 50 Hz para el servo de dirección Savox SC-1251MG 
- Lectura del botón de arranque en GPIO 28 (INPUT_PULLUP, activo LOW) 
- Publicación de telemetría a la Pi5 a 50 Hz vía USB serial 

### **Protocolo Serial de Comunicación RPi5 y Pico2** 

**Pico → Pi5** (50 Hz cada uno): 

POS <x, y, theta, acc_yaw> **`→`** Odometría 
IMU <yaw, qx, qy, qz> **`→`** Quaternión del IMU 
ENC < ticks > **`→`** Conteo del encoder 
BTN **`→`** Botón presionado (evento) 
BOOT,...  OK,...  ERR,... **`→`** Mensajes de estado 

**Pi5 → Pico** (a demanda): 

M < velocidad_ms > **`→`** Velocidad del motor en m/s 
S < direccion > **`→`** Servo, rango [-1.0, +1.0] 
STOP **`→`** Parada de emergencia 

## 6e. Estrategia del Reto Abierto 

La lógica del Reto Abierto está organizada en 4 pilares funcionales, cada uno abordando una preocupación distinta. Esta descomposición hizo más clara la discusión de diseño y modular la implementación. 

### **Pilar 1. Localización y Conteo de Giros** 

Objetivo: saber dónde está el robot y cuántas esquinas ha girado (meta: 12 giros = 3 vueltas completas). 

**Enfoque** : 

- Odometría calculada en el Pico usando los ticks del encoder y el yaw del IMU 

- `theta` publicado normalizado a [-π, +π] 

- `acc_yaw` publicado (valor acumulado del yaw del IMU) 

- Conteo de giros realizado al detectar el cruce (esquina) y no depender del cálculo acumulado del IMU que puede verse afectado por el efecto drifting. 

### **Pilar 2. Detección de Esquinas y Sentido de Recorrido** 

El robot debe detectar cuándo ha llegado a una esquina, decidir hacia qué lado girar, y en qué sentido (CW o CCW) seguirá toda la carrera. Esta metodología era igual a la que empleamos en 2025, pero en aquel momento lo hicimos con ultrasónicos y ahora contamos con un LiDAR, esto nos permitió hacer la detección de una forma más robusta. 

Al encontrarnos a 0,7 metros de la pared central el LiDAR revisa los laterales en busca de aperturas (lecturas mayores a 1m). Sin embargo, no dependimos de una medida única frontal del LiDAR y 2 laterales, le pedimos la mediana de ±5° de la medición frontal y 2° de mediciones laterales en vez de solo una medición a +75° y -75°. En el caso de nuestro LiDAR que nos da 2.160 mediciones en cada vuelta, esto representa 6 mediciones por cada grado, permitiéndonos tener 60 mediciones frontales (10x6) y 12 en cada lateral (2x6), dando más robustez y evitar falsas señales. 

|**Condición**|**Umbral**|**Propósito**|
|---|---|---|
|Distancia frontal cerca|mediana(FRONTAL ±5°) < 0.7 m|Hay una pared al frente|
|Debounce espacial|dist desde último giro > 1.0 m|Evitar contar dos veces<br>la misma esquina|
|Apertura lateral confirmada|mediana(LATERAL 2° en lado<br>del giro) > 1.0 m|Es una esquina real, no<br>una medición errónea|

<table>
  <tr>
    <td align="center">
      <b>Detección Frontal</b><br>
     Frontal70cms
    </td>
    <td align="center">
      <b>Detección Lateral de Esquina</b><br>
      Lateral100cms
    </td>
  </tr>
</table>

```
if self.sentido_giro is None:
    apertura_izq = mediana(LATERAL_IZQ)
    apertura_der = mediana(LATERAL_DER)
    if apertura_izq > 1.0 and apertura_der < 1.0:
        self.sentido_giro = 'CCW'
    elif apertura_der > 1.0 and apertura_izq < 1.0:
        self.sentido_giro = 'CW'
    elif ambos_abiertos:
        self.sentido_giro = 'CCW' if apertura_izq >= apertura_der else 'CW'
    else:
        return  # esperar al siguiente loop, no decidir aún
```

Una vez que en la primera esquina se determina el sentido de los giros, en las siguientes esquinas el LiDAR, solo busca aperturas hacia esa dirección. 

### **Pilar 3. Control de Navegación y Centrado de Pared** 

Establecimos 2 esquemas de control de navegación: El Heading y el Centrado de Paredes donde el que tenga la corrección más importante tiene preferencia. Asi tenemos que: 

**Heading:** Una vez que el LiDAR detecta un desvío importante o detecto un cruce y se actualiza el nuevo ángulo destino +/-90° según sea la dirección, se produce un error alto que activa el heading y hace girar el servo. La agresividad del giro está controlada por un P-controller con dos ganancias diferenciadas. Una ganancia más agresiva (KP_Giro) cuando el error es superior a 15° y una ganancia menor (KP_Rect) cuando el error se reduce a 15°, esto hace que una vez que el error (desviación con el objetivo se reduce) el angulo de giro se suaviza evitando un sobrecruce o oscilaciones buscando el objetivo. 

```
error = norm_ang(self.pose.theta - self.section_angle)

if self.turning:
    str_angle = error * KP_GIRO    # 1.91
else:
    str_angle = error * KP_RECT    # 0.48

str_angle = clamp(str_angle, -1.0, 1.0)
```

**Centrado de Paredes:** Tal como va haciendo las mediciones para detectar las aperturas, también va realizando mediciones para calcular desviaciones respecto al centro de la pista 

Centrado de Paredes

```
dist_der = mediana(WALL_DER)   # +75° a +77° en el frame del robot
dist_izq = mediana(WALL_IZQ)   # -77° a -75° en el frame del robot
```

El algoritmo de centrado no actúa todo el tiempo; solo se activa si se cumplen estas tres condiciones simultáneamente:

```
if (dist_der + dist_izq < 1.1
    and dist_desde_giro > 0.4
    and not self.turning):
```

Esto garantiza que no haya la medición de error cuando hay una apertura, que no se active el centrado cuando está girando o apenas lleva 40cms desde el último giro e interfiera en el giro. 
```
pos = dist_der - dist_izq
    str_lateral = clamp(pos * KP_LATERAL, -0.5, +0.5)
```
<br clear="right" />

Si las condiciones se cumplen, el código calcula cuánto debe corregir la dirección. 

Cálculo del error (pos): Resta la distancia derecha menos la izquierda. 

- Si el robot está perfectamente centrado, dist_der y dist_izq serán iguales, por lo que pos = 0 (no se necesita corrección). 

- Si el robot se arrima a la izquierda, dist_izq se reduce, haciendo que pos sea un valor positivo (orden de corregir hacia la derecha). 

Control Proporcional (Kp): Multiplica ese error por una constante de ganancia (KP_LATERAL). A mayor desviación, mayor será la fuerza del giro corrector, tal como hacíamos en el Heading con 2 Kp. 

Saturación (clamp): Limita el comando de dirección (str_lateral) entre -0.5 y +0.5 para evitar que un cálculo extremo haga que el robot derrape o pierda el control. 

El robot ya viene calculando el Heading (str_heading) apuntando hacia el angulo objetivo. El código compara las magnitudes absolutas del Heading y del Centrado (str_lateral). Si la necesidad de corregir la posición lateral (str_lateral) para no chocar con la pared es más drástica que la de mantener la orientación actual (str_heading), el control de centrado toma prioridad absoluta y devuelve str_lateral. De lo contrario, el robot ignora el centrado fino y sigue su rumbo normal. 

```
if abs(str_lateral) > abs(str_heading):
        return str_lateral    # regla: gana la corrección más fuerte
return str_heading
```

**Velocidad Adaptativa:** Estipulamos 2 velocidades distintas para las curvas y para las rectas, permitiendo la mayor estabilidad. Las velocidades establecidas en 0.25 m/s y 0.4 m/s son el 50% de las velocidades iniciales que establecimos y que están por debajo de la velocidad teórica que habíamos calculado. Sin embargo, está velocidades en la práctica nos permitió tener mayor nivel de confiabilidad y evitar choques por retraso en alguna detección. 

```
if self.turning:
    velocidad = VELOCIDAD_CURVA      # 0.25 m/s
else:
    velocidad = remap(abs(str_angle),
                      in_min=0.0, in_max=1.0,
                      out_min=VELOCIDAD_RECTA,   # 0.4 m/s
                      out_max=VELOCIDAD_CURVA)   # 0.25 m/s
```

### **Pilar 4. Fin de Carrera** 

Después de completarse el 12° giro (turn_count == 12), el estado transita a FINISH_APPROACH, donde: 

- Heading y Centrado de Pared permanecen activos (el robot debe quedarse en el corredor mientras frena) 

- La detección de esquinas se desactiva 

- La velocidad se escalona en tres zonas según la distancia frontal con el objetivo de frenar cuando se encuentre a 1,5 m de la pared frontal (el centro del tramo recto que es de 3,0 metros). Si por alguna razón se pasará de 1,2 m, está abierta la posibilidad de retroceder. 

|**Distancia frontal**|**Velocidad**|**Comportamiento**|
|---|---|---|
|> 2.0 m|VELOCIDAD_RECTA × 0.7 = 0.28 m/s|Aproximación lenta|
|1.5 — 2.0 m|VELOCIDAD_CURVA = 0.25 m/s|Frenado|
|1.2 — 1.5 m|0|Banda de parada objetivo|
|< 1.2 m|-0.2 m/s|Marcha atrás|

### **Máquina de Estados** 

La máquina de estados de alto nivel tiene cinco estados: 

Maquina de Estados Reto1

|**Estado**|**Comportamiento**|
|---|---|
|**BOOT**|Espera el primer scan del LiDAR y el primer mensaje de pose. No<br>inicializa nada más.|
|**READY**|Motor y servo en 0. Espera /start (botón). Al presionar el botón, captura<br>section_angle = theta actual como rumbo de carrera.|
|**RUNNING**|Control completo: detección de esquinas, heading, centrado de pared,<br>velocidad, conteo de giros.|
|**FINISH_APPROACH**|Heading y centrado activos, sin detección de esquinas, perfil de<br>velocidad basado en la distancia frontal.|
|**STOPPED**|Motor y servo en 0. Estado terminal.|

## 6f. Diagrama de Flujo de Reto Abierto

Reto1

### Tiempo de arranque tras encender el robot

Al presionar el interruptor principal de alimentación, el robot tarda aproximadamente **40 segundos** en quedar listo para recibir la señal de inicio (botón físico). Este tiempo se compone de:

| Fase | Tiempo | Descripción |
|---|---|---|
| Boot de Ubuntu 24.04 | 20 s | Carga del kernel Linux, drivers de hardware (USB, I2C, GPIO) y servicios base del sistema, dado que el RPI5 es mas un computador que un simple microcontrolador |
| Espera de detección USB | 5 s | Delay defensivo para asegurar que el Pico Plus 2 (`/dev/ttyACM0`) y el LiDAR STL-27L (`/dev/ttyUSB0`) están correctamente detectados antes de que los nodos intenten conectarse |
| Arranque del driver del LiDAR | 5 s | El LDROBOT STL-27L requiere inicializar su motor de barrido, estabilizar la velocidad de rotación (10 Hz) y publicar el primer scan válido |
| Arranque del bridge del Pico | 5 s | Abre la conexión serial a 921600 baudios, sincroniza con el firmware y confirma que la comunicación bidireccional está activa |
| Arranque del nodo de control | 3 s | Inicializa las suscripciones ROS 2, espera el primer /scan y la primera /npcpos, y transita del estado BOOT al estado READY |
| **Total** | **~40 s** | El robot queda esperando el botón de inicio |

Este tiempo fue contabilizado cargando individualmente cada proceso, los 40 s es una consecuencia del hardware (RPI5) y la arquitectura de software basada en ROS 2 Jazzy sobre Ubuntu 24.04, en contraste con un arranque monolítico tipo Arduino que sería casi instantáneo pero con capacidades muy limitadas. 
La decisión de construir sobre ROS 2 permite modularidad, herramientas de depuración avanzadas y facilidad de integración con sensores complejos (LiDAR, cámara), a costa de un tiempo de arranque.

## 6g. Métricas de Desempeño del Reto Abierto 

Se reportan los avances que fuímos teniendo en pruebas en una pista con las medidas oficiales de la WRO: 

|**Métrica**|**Junio**|**Julio**|**Ago-Sept**|
|---|---|---|---|
|Detección de sentido (CW o CCW)|100% correcta con el enfoque de detección<br>en la primera esquina y luego de ajustes.|Igual|Igual|
|Precisión del conteo de giros|12/12 giros contados correctamente, no se generan dobles giros por restricciones colocadas para ello, aprendidas en WRO 2025|Igual|Igual|
|Tasa de completación de vueltas|Luego de ajustes, Estable con múltiples<br>corridas exitosas de 3 vueltas, 1 solo choque por fallo en lectura de apertura, corregido|100%|100%, excepto en pruebas con mayor velocidad 0,6 m/s donde la efectividad fue 60%|
|Precisión de posición de parada|Consistentemente dentro de la banda 1,2 a 1,5m|Igual|Dentro de la banda de 1,4 a 1,7m al probar con más velocidad|
|Posición lateral durante rectas|< 5 cm de desviación del centro del corredor, mucho más robusto con el control dual Heading y Centrado|Igual|Igual|
|Heading después de completar un giro|Dentro de 5° del objetivo|Igual|Igual|
|Tiempos Promedios en Pruebas| 70 segundos|Se lograron tiempos de 64 seg con mayor velocidad 0,5 m/s, pero las curvas eran mas abiertas, por lo que decidimos mantener en 0,4 m/s, especialmente cuando el centro de la pista era grande 1,8m x 1,8m|Igual, logrando 55seg en algunas pruebas de mas velocidad 0,6 m/s|

En la Regional 1 de Miranda, logramos realizar el reto, pero el robot tardó en arrancar por un problema con el engrane del motor que quedó flojo al consumirse por el calor y la fricción generado por el uso. 

**Solución:** Reimprimir el engranaje en resina de Nylon, mucho mas resistente al calor y a la fricción que el PLA que utilizamos en el engranaje anterior. Una vez solucionados en las prácticas volvimos ha obtener tiempos entre 60 y 70 segundos. 

Resultados Regional 1 2026

En la Regional de Valencia, logramos 27ptos en el reto, pero no se de tuvo. El código que estaba cargado era el del reto 2, que tiene una configuración distinta de culminación de carrera. 

**Solución:** Revisar porque no se habilitó el launcher del Reto 1. Había un problema en el launcher del Reto 1 que estaba en otro directorio, fue solucionado y se hicieron pruebas. 

Tabla de Valencia

## 6h. Nodos y Tópicos de Reto con Obstáculos 

Adicional a los nodos y tópicos del Reto Abierto (Seccion 6a y 6b del Readme), en el Reto con Obstáculos interviene la cámara y por eso se incluye un nodo_camara y tiene su propio codigo de control denominado "control_node_reto2". En cuanto a topicos ademas de los del Reto Abierto se incluye el tópico de detección de los pilares "/pilares"

Nodos y Topicos Reto 2<br>

### Topicos ROS 2 principales

| Topico | Tipo | Publicador → Suscriptor |
|---|---|---|
| /scan | sensor_msgs/LaserScan | lidar → control |
| /npcpos | npc_interfaces/NpcPose | pico_bridge → control |
| /start | std_msgs/Empty | pico_bridge → control (botón físico) |
| /cmd_motor | std_msgs/Float32 (m/s) | control → pico_bridge |
| /cmd_servo | std_msgs/Float32 (−1…+1) | control → pico_bridge |
| /pilares | std_msgs/String (`R:cx:h;G:cx:h;M:cx:h`) | nodo_camara → control_reto2 |

## 6i. Estrategia del Reto con Obstáculos 

La lógica del Reto con Obstáculos está organizada en una navegación distinta a la del Reto Abierdo, donde la detección de esquinas era fundamental para hacer los cruces. En este reto abandonamos eso y si bien mantenemos los Estados simples, la navegación se hace siguiendo 3 capas de orientación que conviven 1) Ruta Proyectada 2) Recorte por Color y 3) SpiderSense.

| Capa | Función | Sensor primario |
|---|---|---|
| **C1 — Ruta Proyectada** | Ray marching: abanico ±60° de candidatos, vecinos ±25°, paso `castR=0.075 m` | LiDAR |
| **C2 — Recorte por color** | Si pilar rojo → solo candidatos derechos; si verde → solo izquierdos | Cámara |
| **C3 — SpiderSense** | Reflejo lateral: si distancia <22 cm en 25°–75°, atenúa el lado correspondiente ÷3 | LiDAR |

### **Capa 1 — Ruta Proyectada (Ray Marching)**

Ruta Proyectada

En la La Capa 1, el LiDAR reporta un abanico de direcciones candidatas frente al robot (de −60° a +60° en intervalos de 2° - 60 lecturas) y cada una se convierte en una "Ruta Viable", entonces para cada una se calcula un "score" para determinar cual es la trayectoria ideal o best_dir. Ese score combina 2 cosas, 1) Cuán lejos puede ir el robot en esa dirección sin chocar con algo y 2) Que tan desviada está esa dirección respecto al rumbo objetivo de la pista. La dirección ganadora es la propuesta inicial de hacia dónde dirigirse.

**Función de score (Capa 1):**
```
score = min(d, DIST_SAT) / DIST_SAT − PESO_RUMBO × |desvío_del_rumbo|
DIST_SAT = 1.6 m       PESO_RUMBO = 0.0015
```

Adicionalmente para cada uno de las 60 rutas candidatas, se aplica el principio de "ray marching" donde no solo se observa el punto candidato si no que también se mide un radio de 7,5 cm de cada lado para cerciorarnos que el robot pueda caber por esa ruta, si en la ruta candidata se choca con algun objeto al ver el ray marching, entonces esa ruta es descartada o su distancia maxima se limita hasta donde si cabe el ray marching.  

<br clear="left" />

### **Capa 2 — Recorte por Color**

Capa2

La cámara aporta dos datos por cada pilar visible: qué color es y en qué posición horizontal de la imagen está (el centro del blob detectado, en píxeles).
El nodo nodo_camara.py convierte cada frame de BGR a HSV, aplica máscaras de color con los rangos HSV calibrados y publica el centroide y la altura del blob más grande de cada color en el topic /pilares. <br>
<br>
La altura en píxeles funciona como proxy de distancia: un pilar cercano se ve grande, uno lejano se ve pequeño. Cuando hay un pilar relevante, la Capa 2 hace una conversión sencilla: traduce la posición en píxeles a un ángulo en el frame del robot usando el FoV de 88° de la lente CCTV 2,8 mm, y luego fuerza el best_dir a un lado u otro del pilar, con un margen seguro de unos 15°. Si el pilar es rojo, el robot se desvía hacia la derecha del pilar, estableciendo una zona prohibida a su izquierda, donde ninguna ruta es factible; mientras que si el pilar es verde, las ruta viables estan hacia la izquierda y las prohibidas a la derecha. 

<br clear="left" />
<br>

### **Capa 3 — SpiderSense**

La Capa 3 "SpiderSense" es el reflejo de emergencia para casos donde las paredes laterales o los obstaculos estan muy cerca, para esto el LiDAR dos sectores laterales (25° a 75° en cada lado del robot) y calcula la distancia mínima en cada uno. Si la distancia del lado izquierdo cae por debajo de 22 cm y el robot está virando hacia la izquierda (steering < 0), entonces el comando de steering se divide entre 3. Lo mismo para el lado derecho. La doble condición (peligro lateral + giro hacia el peligro) es clave, si el robot está virando hacia el lado contrario, no hay riesgo de colisión inminente. Al dividir entre 3 el steering lo que se busca es atenuar el angulo de giro para evitar la colisión lateral 

```
Si d_izq < 22 cm AND robot vira a la izquierda -> steering / 3
Si d_der < 22 cm AND robot vira a la derecha -> steering / 3  
```

### **Fin de carrera:** 

Como no tenemos giros y esquinas como en el Reto Abierto, que para finalizar la carrera, contabamos 12 giros, entonces establecimos una medición acumulada de giro en terminos absoluto del IMU |acc_yaw| y que cuando este supere los 990°, equivalenten a 2,5 vueltas, entonces buscar el proximo color magenta, que justamente es el estacionamiento y cuando lo vea se detenga en esa sección, siguiendo la estrategia del Reto Abierto, es decir, parar cuando este entre 1,3m y 1,5m de la pared frontal de esa sección.

`|acc_yaw| > 990°` **AND** detección de blob
magenta con altura ≥ 60 px (caja de parada), luego parada por
distancia frontal como en Reto 1.

## 6j. Detección de Pilares R/G/M (cámara)

Detección de Pilares

nodo_camara.py convierte el frame BGR a HSV, aplica máscaras de color y publica el centroide y altura del mayor blob de cada color detectado.

**Rangos HSV calibrados en pista oficial (lente CCTV 2.8 mm):**

| Color | H min | H max | S min | S max | V min | V max |
|---|---|---|---|---|---|---|
| **Rojo** (pilar) | 5 | 14 | 80 | 255 | 80 | 255 |
| **Verde** (pilar) | 47 | 96 | 50 | 255 | 60 | 255 |
| **Magenta** (caja de parada) | 158 | 179 | 70 | 255 | 70 | 255 |

**Nota crítica del rojo:** H_min = 5` está deliberadamente arriba de 0 para evitar las líneas naranjas del piso de la pista WRO, confusión que sucedieron en las primeras prácticas. 

<br clear="left" />
<br>

## 6k. Diagrama de Flujo de Reto con Obstáculos

Reto2

## 6l. Métricas de Desempeño del Reto con Obstáculos 

Se reportan los avances evolutivos que fuímos teniendo en pruebas en una pista con las medidas oficiales de la WRO: 

|**Métrica**|**Junio**|**Julio**|**Ago-Sept**|
|---|---|---|---|
|Detección de Ruta Ideal)|100% correcta cuando se practica sin obstaculos (12 rondas de 3 vueltas c/u). Con obstaculos (200 obstaculos con promedio de 5 por vuelta de 40 vueltas). <br> En el 10% de los casos la evasión ha causado un desvio incorrecto (21/200)| Con obstaculos (357 obstaculos con promedio de 7 por vuelta de 51 vueltas). En el 10% de los casos la evasión ha causado un desvio incorrecto (36/350)|420 obstaculos con promedio de 7 por vuelta de 60 vueltas. En el 6% de los casos la evasión ha causado un desvio incorrecto (25/420) |
|Tasa de Detección de Obstáculos|96% de obstaculos detectados correctamente (192/200 obstaculos). <br>  Dificultad de detección cuando vehículo se desvia mucho y cámara no detecta por el FoV|98% de obstaculos detectados correctamente|90% de obstaculos detectados correctamente, se practicó con ubicación de obstaculos compleja|
|Tasa de Evasión de Obstáculos|80% de obstaculos detectados correctamente (160/200 obstaculos). <br> 4% por no detección, 10% por falta de espacio para evadir y 6% por chocar el obstáculo|85%|89%|
|Tasa de completación de vueltas|40% de Éxito de vuelta completa con evasión (16 de 40 vueltas). Ha mejorado desde que redujimos velocidad.|50%|90% aunque mueve algún pilar|
|Precisión de posición de parada|0% Se está deteniendo un giro antes por detección erronea del magenta. Identificado el problema pero dando prioridad a otros ajustes|Igual|40%, aun con problemas con el magnenta|
|Tiempos Promedios en Pruebas| 32 segundos por Vuelta|35 seg por vuelta|38 seg por Vuelta, hemos logrado mas eficiencia con menor velocidad|

## 6m. Ajustes Realizados en Ambos Retos

- Inicialmente diseñamos una detección de sentido pre-arranque más ambiciosa analizando discontinuidades del LiDAR mientras el robot estaba estacionario. La idea era detectar el lado en donde estaban las discontinuidades más importantes, para detectar hacia qué lado estaba la apertura, pero la tasa de éxito dependía mucho de la posición inicial del robot por lo que pasamos a una estrategia más reactiva como la comentada en el _Pilar 2 - Sección 6e. Estrategia del Reto Abierto_. 

- Al comienzo habíamos establecido, que una vez que el robot comenzara a girar, saliera del modo giro cuando el error con respecto al ángulo objetivo ya se hubiera reducido a 45° (la mitad), esto para evitar sobregiros por la velocidad pasando el P Controller de un KP_GIRO más alto a  KP_RECT mas gradual, pero obtuvimos muchos subgiros y activación de aperturas no reales que provocaban nuevos giros. La solución: 

   - Luego de un proceso iterativo redujimos el error para pasar de KP_GIRO a KP_RECT de 45° a 15° 
   - Redujimos las velocidades a la mitad, quedando en 0.4 m/s en rectas y 0.25 m/s en curvas. Favoreciendo confiabilidad vs velocidad. 

Con estos ajustes logramos una tasa de éxito muy elevada en el Reto Abierto, incluso con cambios en el tamaño del cuadro central a 1,4m y 1,8m por lado. La velocidad reducida y el esquema dual del P-Controller han permitido que los ajustes post giro se han muy leves y a veces imperceptibles. 

- **Proyecto Mahoraga** en el Reto con Obstáculos arrancaba todo el tiempo recto y no cruzaba pese a detectar rutas en las aperturas, razón por lo que tuvimos que recalibrar el mecanismo de score que daba a cada ruta candidata, disminuyendo la penalización de no ir a la dirección actual. Pese a recalibrar, logramos el efecto contrario donde siempre se inclinaba con mas fuerza a donde hubiera la mayor apertura, provocando giros mas agresivos hacia la ruta ideal, está pendiente evaluar si limitar el giro maximo que podía hacer en cada iteracción para suavizar el comportamiento.

- Para el Reto con Obstáculos también vimos la necesidad de reducir la velocidad y así dar mas tiempo para la detección de obstáculos y la maniobra de evasión, quedando en 0.3 m/s en rectas y 0.20 m/s en curvas.

- La magnitud del giro en Ruta Proyectada (Capa 1) viene determinada por el grado donde se encuentra la ruta ideal en un campo de -60° a +60°, si está en alguno de los extremos el servo gira al máximo posible hacia ese lado, en una función lineal que determinaba el angulo de giro. Si el angulo de la ruta ideal, era por ejemplo +30°, ahi el giro era el 50% del máximo del servo. Entonces, lo que hicimos fue cambiar la función lineal Giro del Servo (-100%,100%) = Angulo de Ruta Ideal / 60 a una función servo donde (Angulo de Ruta Ideal/60)^k con k < 1. Esto permite que el ajuste sea mas agresivo, pese a que los valores no sean extremos garantizando una reacción mas acelerada. Nos queda es encontrar el valor de K que sea ideal para tener el trade off entre mayor agresividad de giro sin generar volatilidad en el recorrido por cambios bruscos del servo.

- Producto del mayor nivel de giro, lateralmente Proyecto Mahoraga podía mover algunos de los pilares, 2 o 3 por vuelta, por lo que incluimos un delay despues de deja de ver el obstaculo de 1.5 seg antes de cambiar de dirección.

Con estos ajustes hemos logrado una mejora en la tasa de éxito en el Reto con Obstáculos, hemos descartado estructurar una maniobra de retroceso cuando no sea posible hacer la evasión del obstáculo, dado que cambiaría en mucho la lógica de conducción y ya hemos minimizando esos casos. Sigue pendiente unae strategía eficaz del estacionamiento.

## 7. Pensamiento Sistémico y Decisiones de Ingeniería (Criterio 4)

Esta sección documenta cómo los subsistemas del robot trabajan juntos, las restricciones que dieron forma al diseño, las decisiones principales con sus alternativas, y el historial de iteraciones.

## 7a. Diagrama de Bloques del Sistema

Diagrama de Subsistemas

## 7b. Interacción entre Subsistemas

| Subsistema A | Subsistema B | Interacción |
|---|---|---|
| LiDAR STL-27L | Control (RPi 5) | Publica /scan a 10 Hz → control extrae sectores frontal/laterales |
| Cámara GS + lente 2.8 mm | Nodo de visión (RPi 5) | Detecta pilares R/G/M y publica /pilares (formato R:cx:h;G:cx:h) |
| Pico Plus 2 | RPi 5 | UART USB 921600 baud, CSV → topics /npcpos, /imu, /encoder, /start |
| IMU BNO085 | Pico Plus 2 | I²C 100 Hz → integración con encoder produce POS,x,y,θ,acc_yaw |
| Encoder motor | Pico Plus 2 | Interrupción RISING en GP2 + lectura GP3 → odometría a 100 Hz |
| Control (RPi 5) | Pico Plus 2 | Publica /cmd_motor (m/s) y /cmd_servo (-1..+1) a 40 Hz |
| Pico Plus 2 | VNH5019 | INA/INB + PWM 20 kHz (GP8/9/12) → tracción |
| Pico Plus 2 | Servo Savox | PWM 50 Hz en GP15 → dirección Ackermann |
| ToF VL53L4CD ×2 | Pico Plus 2 | I²C vía Qwiic MultiPort, reservados para parking Reto 2 |
| Botón físico (GP28) | Pico Plus 2 → RPi 5 | Publica /start → control captura section_angle al arrancar |

## 7c. Restricciones (Constraints) Identificadas

| Restricción | Límite | Impacto en el diseño |
|---|---|---|
| Dimensiones máximas | 300 × 200 × 300 mm (regla WRO 2026) | Llevó a chasis personalizado 230×150×126 mm |
| Peso máximo | 1500 g | El robot final pesa 1.100 g (margen +400 g) |
| Altura paredes pista | 10 cm | Forzó LiDAR al primer piso adelantado para barrer a la altura correcta |
| Altura pilares (Reto 2) | ~10 cm coloreados R/G | Forzó lente CCTV 2.8 mm (FoV 96°) y angulo de 60° para capturar pilares cercanos |
| FoV útil del LiDAR | Solo 193°–350° (157° hacia adelante) | Todos los sectores del control deben estar dentro de ese rango |
| Voltaje mínimo bus motor | 12 V nominal | Forzó LiPo 3S (2S no era suficiente) |
| Pico de corriente servo | hasta 3.5 A | Forzó regulador 5V dedicado al servo (D36V50F5) |
| Sin Wi-Fi en la pista | 0 conectividad | Arranque autónomo vía systemd + botón físico |
| Tiempo de boot | ~40 s | Aceptado: priorizamos estabilidad sobre velocidad |

## 7d. Decisiones de Diseño Principales

Esta subsección resume las decisiones de ingeniería más importantes con su razonamiento. 
**Cada decisión sigue el patrón "elegimos X en vez de Y porque…"** Aunque la comparativa de componentes se puede ver con detalle en la carpeta ***Selección de Componentes y Comparación con 2025***.

### Decisión 1 — Arquitectura: RPi 5 como Cerebro + Pico 2 como ejecutor y reportador de datos 

| Opciones consideradas | Veredicto |
|---|---|
| **A: Toda la lógica en RPi 5, Pico solo sensores y actuadores** | ✓ **Elegida** |
| B: Lógica distribuida (RPi 5 alto nivel, Pico control local) | Descartada |
| C: Todo en Pico, sin Pi 5 | Descartada |

**Por qué A:** Python en la RPi 5 acelera la iteración de algoritmos
(ROS 2, OpenCV); el Pico ofrece tiempo real estricto para encoder e
IMU; la frontera entre los dos es un protocolo CSV legible. **El
Pico es deliberadamente ejecutor:** no decide, solo ejecuta.

### Decisión 2 — Arquitectura: Elección de ROS 2

La decisión de construir el software del robot sobre **ROS 2 Jazzy** en lugar de un enfoque monolítico tipo Arduino nos aportó ventajas técnicas para un proyecto de esta complejidad. El sistema de topics permite que los sensores (LiDAR, IMU, encoder), el nodo puente al Pico y el nodo de control se comuniquen de forma desacoplada y asíncrona, lo que facilitó desarrollar y depurar cada componente por separado. Herramientas como /pilares, Rviz2, y el uso de SSH, permitieron diagnosticar en tiempo real qué estaba viendo el robot y por qué tomaba cada decisión. Finalmente, el modelo de mensajes personalizados (como nuestra `NpcPose.msg`) nos garantiza coherencia temporal entre los datos de odometría, y prepara la arquitectura para escalar al Reto de Obstáculos con la incorporación natural de nuevos nodos (visión por cámara, sensores ToF) sin reescribir la lógica existente. 

### Decisión 3 — Lógica del Reto Abierto: 4 pilares en lugar de máquina de estados compleja

| Pilares | Función |
|---|---|
| **Pilar 1** | Localización (odometría) y conteo de **12 giros** (interpretación más robusta) |
| **Pilar 2** | Detección de esquinas (mediana frontal + confirmación lateral + debounce espacial) |
| **Pilar 3** | Control en 3 capas (heading, wall-centering, velocidad adaptativa) |
| **Pilar 4** | Fin de carrera con banda de parada 1,2 a 1,5m |

**Por qué 4 pilares y no máquina de estados grande:** la máquina se reduce a solo 5 estados (`BOOT → READY → RUNNING → FINISH_APPROACH → STOPPED`); el resto de la complejidad vive como capas dentro del estado `RUNNING`, fácil de ajustar capa por capa sin tocar las otras.

### Decisión 4 — Reto con Obstáculos: Siguiendo Camino de 3 capas

| Capa | Función | Sensor principal |
|---|---|---|
| **Capa 1 — Ruta Proyectada** | Ray marching para encontrar la mejor dirección libre | LiDAR |
| **Capa 2 — Recorte por color** | Rutas posibles se limitan según color del pilar (rojo→derecha, verde→izquierda) | Cámara |
| **Capa 3 — SpiderSense** | Reflejo lateral de emergencia si un pilar o pared se acerca demasiado | LiDAR |

**Por qué navegación reactiva y no detección de eventos:** la busqueda de ruta más profunda maneja curvas y pilares implícitamente, sin la necesidad de "detección
de esquina, que es mas dificil en la presencia de obstaculos. La cámara es solo semáforo de color (rojo/verde), no estima distancia. La distancia la lleva el LiDAR.

### Decisión 5 — Conteo de vueltas por yaw acumulado, no por esquinas

**Por qué |acc_yaw| > 990° en Reto 2** (en lugar de contar giros como en Reto 1): los pilares fuerzan trayectorias no rectangulares; el robot puede "girar" 90° por una curva *o* por una evasión, y
contar esquinas confundiría ambas. El yaw acumulado es robusto en ambos casos con 990°, es equivalente a 11 giros y solo debe para en el siguiente giro cuando vea el color MAaenta. Solo hay que configurar bien el color Magenta.

### Decisión 6 — Detección de sentido CW/CCW en la primera esquina

**Antes:** intentábamos detectar sentido con discontinuidades del LiDAR antes de arrancar (robot quieto).
**Problema:** en pruebas no funcionaba consistentemente.
**Decisión:** adoptar enfoque de esperar a la primera esquina y elegir el lado con apertura.
**Resultado:** robusto, se eliminó un estado `DETECTING_SENSE` que estaba presente en una versión inicial del Reto 1.

## 7.e Análisis de Riesgos y Mitigación

| Riesgo | Probabilidad | Impacto | Mitigación implementada |
|---|---|---|---|
| Caída del riel 5V por pico del servo | **Alto** | Reset de la RPi 5 a mitad de carrera | **Regulador dedicado al servo** (D36V50F5) |
| EMI del motor sobre IMU | Media | Yaw inestable | IMU en piso superior + canales de cable separados |
| LiDAR no ve paredes de 10 cm | **Alta si mal montado** | Imposibilidad de centrarse | **LiDAR en primer piso, no en piso superior** |
| ToF lee basura a <15 mm | Media | Lecturas espurias en parking | Sensor retraído ≥15 mm + filtro software |
| Cámara sin rolling shutter distorsiona | Media | Falsos positivos de pilar | Global shutter elegida específicamente |
| Variación de iluminación en pista | Alta | Falla detección de color | Calibración HSV in-situ con `calibrador_hsv.py` |
| Pérdida de comunicación Pi ↔ Pico | Baja | Robot fuera de control | Reconexión USB automática en bridge |
| Robot atascado contra pared | Media | Pérdida de la ronda | SpiderSense reflejo lateral (Capa 3 Reto 2) |

## 7.f Historial de Iteraciones (resumen)

| Versión | Cambio principal | Resultado |
|---|---|---|
| **V0.1** | Diseño inicial 3 pisos, motor 20.4:1, batería 2S, LiDAR arriba, 1 sólo regulador | Demasiado alto, potencia insuficiente, LiDAR no ve paredes bajas o montarlo volteado como algunos equipos |
| **V1.0** | Rediseño chasis 2 pisos + compartimiento de batería, motor 34:1, batería 3S, servo Savox SC-1251MG digital, LiDAR abajo y adelante + 2 reguladores | Geometría compacta, Ackermann real, LiDAR ve paredes, Mejor distribucción de energía |
| **V2.0** | Compartimiento de batería y repisa, generaron un subnivel para ubicar IMU y botón de arranque, asi como mejorar cableado| Sistema robusto, cableado limpio, sin necesidad de 3er Nivel **✓** |
| **Reto Abierto V1** | 4 pilares con detección de sentido pre-arranque | No funcionaba consistentemente |
| **Reto Abierto V2** | Detección de Sentido por 1era Esquina, Reducción de Velocidad y Ajuste del P Control  | Estabilidad y Alta Tasa de Ëxito del Reto Abierto **✓** |
| **Reto con Obstaculos V1** | Gap follower de 3 capas "Siguiendo Camino-RecortexColor y SpiderSense" | Aún en ajustes, con cambios en parametros y velocidad para dar mas tiempo de respuesta  |

# 8. Instrucciones de Reproducibilidad (Criterio 5)

 Esta sección permite que otro equipo pueda replicar el robot **Proyecto Mahoraga** desde cero. Incluye lista de hardware con links de compra, requisitos de software, instalación paso a paso, estructura del repositorio, archivos CAD/3D y procedimiento de arranque en
competencia. Sin embargo, el Journal del paso a paso que nosotros hicimos está en las sección **Journal** del Repositorio.

## 8.a Requisitos de Hardware

Para facilitar su reproductibilidad anexamos lista completa de los componentes con los enlaces de compra de cada componente.<br>

| Categoría | Componente | Modelo / SKU | Cant. | Link |
|---|---|---|---|---|
| **Cómputo** | SBC alto nivel | Raspberry Pi 5 — 16 GB RAM | 1 | [Adafruit 6125](https://www.adafruit.com/product/6125) |
| | Refrigeración | Official Raspberry Pi 5 Active Cooler | 1 | [Adafruit 5815](https://www.adafruit.com/product/5815) |
| | Base NVMe | Pimoroni NVMe Base PIM699 | 1 | [Adafruit 5845](https://www.adafruit.com/product/5845) |
| | SSD | Silicon Power 128 GB M.2 NVMe Gen3 | 1 | Amazon |
| | MicroSD (backup) | Silicon Power 32 GB | 1 | Amazon |
| | Microcontrolador | Pimoroni Pico Plus 2 (RP2350) PIM724 | 1 | [Adafruit 6244](https://www.adafruit.com/product/6244) |
| | Adapter terminal | Adafruit Terminal PiCowbell con sockets | 1 | [Adafruit 5907](https://www.adafruit.com/product/5907) |
| **Sensores** | LiDAR 360° | LDROBOT STL-27L (25 m) | 1 | [DFRobot 2726](https://www.dfrobot.com/product-2726.html) |
| | Cámara | Raspberry Pi Global Shutter (IMX296) | 1 | [Adafruit 5702](https://www.adafruit.com/product/5702) |
| | Lente cámara | CCTV M12 2.8 mm F2.0 1/2.7" | 1 | Amazon |
| | Cable cámara | FPC 22-pin → 15-pin, 200 mm (RPi 5) | 1 | [Adafruit 5818](https://www.adafruit.com/product/5818) |
| | ToF láser | Adafruit VL53L4CD STEMMA QT | 2 | [Adafruit 5396](https://www.adafruit.com/product/5396) |
| | IMU 9-DOF | Adafruit BNO085 STEMMA QT | 1 | [Adafruit 4754](https://www.adafruit.com/product/4754) |
| | Concentrador I²C | SparkFun Qwiic MultiPort | 1 | [SparkFun](https://www.sparkfun.com/sparkfun-qwiic-multiport.html) |
| | Cable Qwiic | Flexible Qwiic Cable 50 mm | 4 | [SparkFun](https://www.sparkfun.com/flexible-qwiic-cable-50mm.html) |
| **Actuadores** | Motor + encoder | Pololu 34:1 25Dx67L MP 12V + encoder 48 CPR | 1 | [Pololu 4864](https://www.pololu.com/product/4864) |
| | Driver de motor | Pololu VNH5019 Motor Driver Carrier | 1 | [Pololu 1451](https://www.pololu.com/product/1451) |
| | Servo de dirección | Savox SC-1251MG digital coreless | 1 | [Savox](https://savox-servo.com/en/product/SC-1251MGplus/savox-servo-sc-1251mg-digital-coreless-motor-metal-gear) |
| **Potencia** | Batería | Zeee LiPo 3S 11.1 V 3200 mAh 50C | 1 | [Zeee Battery](https://zeeebattery.com/collections/zeee-3s-lipo-battery/products/zeee-3s-lipo-battery-3200mah-11-1v-50c-deans-t) |
| | Regulador 5V — Lógica | Pololu D24V90F5 (5 V, 9 A) | 1 | [Pololu 2866](https://www.pololu.com/product/2866) |
| | Regulador 5V — Servo | Pololu D36V50F5 (5 V, 5.5 A) | 1 | [Pololu 4091](https://www.pololu.com/product/4091) |
| **Mecánica** | Ruedas | 64 mm aluminio + neumático goma | 4 | Amazon |
| | Eje trasero | KYX Racing Steel Drive Shaft (Tamiya DT04) | 1 | Amazon |
| | Manguetas Ackermann | KYX Racing Aluminum Steering Knuckles | 2 | Amazon |
| | Servo saver | Tamiya TT-02 Hi-Torque | 1 | [Tamiya](https://www.tamiyausa.com/). |
| | Tie rods | M3 ajustables uxcell | 2 | Amazon |
| | Ejes | Acero inoxidable 5 mm × 100 mm uxcell | 2 | Amazon |
| **Cables** | USB-C Pi↔Pico | SUNGUY USB-C 3.1 Gen2 — 6 in y 1 ft | 2 | Amazon |
| **Mecánica 3D** | Filamento | PLA Bambu Lab | — | Bambu Lab |
| | Impresora 3D | Bambu Lab P2S | — | Bambu Lab |

**Listado de impresiones 3D** 

Se realizó un Anexo de la Sección 8.1. dedicado a todas las Piezas 3D, su distintas evoluciones, fotos de su prototipo, versiones en 3D y Foto del componente ya impreso. El anexo está disponible [**/materials/Piezas 3D.md**](https://github.com/NPC2team/NPC2-WRO-team-2026/blob/main/materials/Piezas%203D.md)

Los componentes impresos en 3D tienen sus archivos en STL/3MF en **/models.** 

||Formato|Formato|
|---|---|---|
|Pieza|3mf|STL|
|Canal 2 Cables Tapa|x|x|
|Canal 3 Cables Tapa|x|x|
|Canal 4 Cables Tapa|x|x|
|Canal 2 Cables|x|x|
|Canal 3 Cables|x|x|
|Canal 4 Cables|x|x|
|Chasis Abajo V2|x|x|
|Chasis Arriba V2|x|x|
|Espaciador de Eje|x|x|
|Gear Box Diferencial|x|x|
|Gear Diferencial|x|x|
|Gear Motor con<br>Flange|x|x|
|Repisa|x|x|
|Soporte Motor VF|x|x|
|Soporte Servo VF|x|x|
|Sujetador de Cables|x|x|

### Configuración de impresión recomendada

```
Material:    PLA Bambu Lab
Boquilla:    0.4 mm
Capa:        0.2 mm
Perímetros:  3
Infill:      25 % (55 % para Chasis)
Soportes:    Sí - Tipo árbol
Impresora:   Bambu Lab P2S
```

## 8.b Requisitos de Software

### En la Raspberry Pi 5

```
- Ubuntu 24.04 LTS (Server, no Desktop, para arranque rápido)
- ROS 2 Jazzy Jalisco
- Python 3.12
- OpenCV 4.x (apt install python3-opencv)
- Driver oficial LDROBOT ldlidar_stl_ros2
- Workspace npc_ws con paquetes npc_bot y npc_interfaces
- systemd service npc_bot.service (auto-arranque)
```

### En la laptop de desarrollo

```
- Ubuntu 24.04 LTS (Desktop, en nustro caso hicimos una partición separada a Windows)
- Arduino IDE 2.3.8
- Board package: Earle Philhower RP2350 (para Pico Plus 2)
- Librerías Arduino: Adafruit BNO08x, SparkFun VL53L4CD
- Visual Studio Code
- Autodesk Fusion 360 (CAD)
- Bambu Studio (laminado e impresión)
- Git
```

## 8.c Instalación Paso a Paso

### 1) Preparar la Raspberry Pi 5

```bash
# Sistema operativo Ubuntu 24.04
sudo apt update && sudo apt upgrade -y
sudo apt install -y python3-opencv python3-numpy python3-pip

# ROS 2 Jazzy Jalisco
# https://docs.ros.org/en/jazzy/Installation/Ubuntu-Install-Debs.html
sudo apt install -y ros-jazzy-desktop ros-jazzy-cv-bridge
echo "source /opt/ros/jazzy/setup.bash" >> ~/.bashrc
```

### 2) Workspace LiDAR

```bash
mkdir -p ~/lidar_ws/src && cd ~/lidar_ws/src
git clone https://github.com/ldrobotSensorTeam/ldlidar_stl_ros2.git
cd ~/lidar_ws
colcon build
echo "source ~/lidar_ws/install/setup.bash" >> ~/.bashrc
```

### 3) Workspace de la cámara (camera_ros)

```bash
mkdir -p ~/camera_ws/src && cd ~/camera_ws/src
git clone https://github.com/christianrauch/camera_ros.git
cd ~/camera_ws
colcon build
echo "source ~/camera_ws/install/setup.bash" >> ~/.bashrc
```

### 4) Workspace principal (npc_bot)

```bash
mkdir -p ~/wro_ws/src && cd ~/wro_ws/src
git clone https://github.com/[equipo-NPC]/wro2026-future-engineers.git npc_bot
cd ~/wro_ws
colcon build
echo "source ~/wro_ws/install/setup.bash" >> ~/.bashrc
```

### 5) Cargar firmware al Pico Plus 2

```
1. Conectar Pico Plus 2 vía USB a la laptop
2. Abrir src/firmware/pico_firmware.ino en Arduino IDE 2.3.8
3. Seleccionar Board: "Pimoroni Pico Plus 2 (RP2350)"
4. Seleccionar puerto serial correcto
5. Click Subir (Upload)
```

### 6) Calibración HSV de la cámara (Reto 2)

 Interfaz interactiva con sliders para calibrar rangos HSV de rojo, verde y magenta. 

```bash
ros2 run npc_bot calibrador_hsv
```

### 7) Servicio systemd (auto-arranque, requerido por reglas WRO 9.6–9.14)

```bash
sudo cp src/systemd/npc_bot.service /etc/systemd/system/
sudo systemctl daemon-reload
sudo systemctl enable npc_bot.service
sudo systemctl start npc_bot.service
```

Tiempo de boot hasta robot listo: **~40 segundos** desde encendido al pitido de "READY".

## 8.d Estructura del Repositorio

```
/
├── README.md                  ← este documento (índice maestro)
├── LICENSE
├── journal/                   ← Engineering Journal (extendido)
│   ├── README.md
│   
├── src/                       ← código fuente
│   ├── firmware/
│   │   └── pico_firmware.ino  ← firmware Pico Plus 2 (Arduino)
│   ├── npc_bot/               ← paquete ROS 2 Python
│   │   ├── pico_bridge_node.py
│   │   ├── control_node.py             (Reto 1 — Open Challenge)
│   │   ├── control_node_reto2.py       (Reto 2 — Obstacle Challenge)
│   │   ├── nodo_camara.py              (visión Reto 2)
│   │   └── calibrador_hsv.py           (calibración interactiva)
│   ├── npc_interfaces/        ← paquete ROS 2 con mensajes custom
│   │   └── msg/NpcPose.msg    ← {x, y, theta, acc_yaw}
│   ├── launch/                ← launch files
│   │   ├── npc_bot.launch.py           (Reto 1)
│   │   └── base_reto2.launch.py        (Reto 2)
│   └── systemd/
│       └── npc_bot.service    ← arranque automático
├── models/                    ← archivos CAD/3D
│   ├── *.stl                  ← geometría imprimible
│   ├── *.3mf                  ← proyectos Bambu Studio
│   └── *.step                 ← modelos (motor Pololu)
├── schemes/                   ← diagramas eléctricos
│   ├── conexiones-del-robot.pdf
│   └── diagrams/
│       ├── wiring.png
│       ├── mechanical.png
│       └── system_overview.png
├── t-photos/                  ← fotos del equipo
│   
├── v-photos/                  ← fotos del vehículo (6 ángulos)
│   ├── front.jpg
│   ├── back.jpg
│   ├── left.jpg
│   ├── right.jpg
│   ├── top.jpg
│   └── bottom.jpg
└── video/
    └── video.md               ← link a video de demostración (YouTube)
```

## 8.e Cómo Arrancar el Sistema

### Opción A — Arranque automático (En competencia)

```
1. Conectar batería LiPo 3S
2. Encender interruptor principal
3. Esperar ~40 s (LED indicador en verde fijo = listo)
4. Colocar robot en la pista en posición de salida
5. Presionar botón físico (GP28) → el robot captura section_angle
   y arranca la lógica de carrera
```

### Opción B — Arranque manual (En prácticas para depuración)

Terminal 1 — LiDAR:
```bash
ros2 launch ldlidar_stl_ros2 stl27l.launch.py
```

Terminal 2 — Bridge del Pico:
```bash
ros2 run npc_bot pico_bridge
```

Terminal 3 — Control (elegir uno según el reto):
```bash
ros2 run npc_bot control_node           # Reto 1: Open Challenge
ros2 run npc_bot control_node_reto2     # Reto 2: Obstacle Challenge
```

Terminal 4 (solo Reto 2) — Cámara + visión:
```bash
ros2 launch npc_bot base_reto2.launch.py
```

## 8.f Notas de Ensamblaje

Resumen del orden recomendado:

1.  Imprimir todas las piezas
2.  Ensamblar diferencial: insertar engranajes cónicos en `Gear Box Diferencial`
3.  Montar eje trasero KYX con diferencial en el `Chasis Abajo` ajustando con sus Sortes y Espaciadores.
5.  Montar Motor Pololu 34:1 con `Soporte Motor` y `Gear Motor con Flange`
6.  Montar servo Savox detrás de las ruedas delanteras en su `Soporte Servo VF`
7.  Conectar manguetas KYX + tie rods M3 + servo saver Tamiya
8.  Ajustar alineación con servo centrado
9.  Colocación del LiDAR STL27L
10. Colocar Soportes y Chasis de Arriba
11. Montar VNH5019, reguladores con batería LiPO S3 en el primer piso
12. Montar Raspberry Pi 5 y Pico Plus 2
13. Colocación de Sensores TOF e IMU + Botón de Inicio
14. Ruteo de cables por los canales modulares y agujeros del Chasis 
15. Colocación de Cámara

<table>
  <tr>
    <td align="center">
      <b>Ensamble del Diferencial</b><br>
      01 Diferencial con Soporte
    </td>
    <td align="center">
      <b>Soportes del Diferencial + Ruedas</b><br>
      02 Diferencial con Ruedas
    </td>
    <td align="center">
      <b>Montaje del Motor</b><br>
      03 Motor
    </td>
  </tr>
   <tr>
    <td align="center">
      El diferencial va ajustado en el espacio considerado en el chasis para él, colocando los primeros soportes y los espaciadores hechos a la medida para garantizar que la caja del diferencial no se deslice de lado cuando gire el motor<br>
    </td>
    <td align="center">
      El otro par de soportes se incluyen para evitar que no quede recto la transmisión, como pasaba en la versión anterior del Chasis por el peso de la caja del diferencial. Se ajustan las ruedas y se revisa que queden bien sujetas y a la misma distancia del chasis a cada lado.<br>
    </td>
    <td align="center">
      Los agujeros del chasis garantizan que el soporte del motor quede ubicado donde los engranajes del motor y del diferencial estan alineados. Importante que el nuevo enganaje del Motor impreso en Nylon, permite a diferencia del PLA utilizado antes mayor resistencia a la fricción.<br>
    </td>
  </tr>
   <tr>
    <td align="center">
      <b>Montaje de Dirección</b><br>
      05 Servo
    </td>
  <td align="center">
  <b>Colocación del LiDAR</b><br>
  06 LiDAR
</td>
    <td align="center">
      <b>Colocación del Chasis Superior</b><br>
      08 Chasis Arriba
    </td>
  </tr>
<tr>
    <td align="center">
     Las barras se atornillan a las manguetas y estas a las C-Hubs del chasis. Las tierods son ajustables para lograr la alineación con el centro del servo. El soporte del servo se fija al chasis y se atornilla el tierod al Servo Saver. Para armar el Servo Saver, dejamos un <a href="https://www.youtube.com/watch?v=pzWLF9ScBSY" target="_blank">Link</a> que nos ayudó. <br>
    </td>
    <td align="center">
      El LiDAR se atornilla en la parte frontal asegurando que quede fijo y garantice un Field of View de 180 grados. <br>
    </td>
    <td align="center">
      Los agujeros del chasis superior e inferior estan alineados para colocar los soportes de 6cms y así unir ambos chasis, garantizando el espacio con holgura para que los componentes y el subnivel de la bateria entren sin problema.<br>
    </td>
  </tr>
</table>
---
<table>
  <tr>
    <td align="center">
      <b>Colocación de Driver del Motor y Regulador</b><br>
      09 VNH + Reg
    </td>
    <td align="center">
      <b>Regulador del Servo</b><br>
      10 Conexion Reg Servo
    </td>
    <td align="center">
      <b>Colocación de Pico 2 Plus</b><br>
      15 Conexion Pico 2 Plus
    </td>
  </tr>
  <tr>
    <td align="center">
     Continuamos con la parte eléctrica, colocando el VNH5019 y el Regulador Cenral que reciben energía de la batería a través del switche de encendido. Para el detalle del cableado ver la sección 5 del Readme o del Journal. <br>
    </td>
    <td align="center">
      Arriba en la parte frontal ubicamos el regulador D36V50F5, encargado exclusivamente del servo. Recibe la energía a través del switche y la envía al Servo. Pasamos los cables por los agujeros del chasis para conectar con el sevo qque está abajo. Para asegurar los cables Dupont utilizamos un sujetador.<br>
    </td>
    <td align="center">
      Encima del compartimiento de la batería ubicamos el Pico 2 Plus. Queda centrado en el vehículo, lo cual era importante porque es el que mas conexiones lleva (VNH5019, Encoder, Botón de Arranque, RPI5, IMU y TOF). <br>
    </td>
  </tr>
   <tr>
    <td align="center">
      <b>Colocación de RPI 5</b><br>
      131 RPI5
    </td>
  <td align="center">
  <b>Botón + IMU BNO085</b><br>
  16 IMU + Boton
</td>
    <td align="center">
      <b>Foto Final</b><br>
       17 Foto Final
    </td>
  </tr>
   <tr>
    <td align="center">
     La RPI5 la ubicamos en la parte trasera y sus conexiones principales son con el Pico 2 Plus y el LiDAR, como la comunicación es por USB es importante tener cables muy cercanos a la medida necesaria. Para armar el NVME seguimos el paso a paso de la pagina oficial de <a href="https://learn.pimoroni.com/article/getting-started-with-nvme-base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" target="_blank">Pimoroni</a>. <br>
    </td>
    <td align="center">
      Al lado del Pico 2 Plus, colocamos una protoboard y ahi encajamos el Botón de Inicio y el IMU BNO085, asegurandonos que no utilicen las misma lineas de conexión. Si bien el IMU se conecta por Qwiic los pines pueden interferir.<br>
    </td>
    <td align="center">
      Colocación de la Cámara en su soporte en el Piso de Arriba con 60 grados de inclinación. <b>Proyecto Mahoraga</b> queda totalmente armado y listo luego de ajustar cableado (Sección 5) y la programación (Sección 6 y 7).<br>
    </td>
  </tr>
</table>

## 8.g Journal Detallado

Acá presentamos el Gantt que se construyó con el detalle de las fases que llevamos acabo como equipo para poder desarrollar a Proyecto Mahoraga. En la carpeta de ***Journal*** veran el detalle de cada una de estas fases semana a semana y por hito y que no colocamos aquí por lo amplio de la información.

Cronograma

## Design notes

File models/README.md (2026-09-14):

**En este archivo encontraras todas los archivos 3D que imprimimos para ser usados para el robot.
En este archivo encontraras distintos modelos, algunos viejos que tienen sus versiones nuevas como el Chassis arriba que tiene una version 2.

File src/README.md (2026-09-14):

**En esta carpeta encontraras diferentes archivos que estan relacionados con la programación del carro o sus componentes.**
Los archivos de los nodos de la camara y los 2 nodos de control para cada uno de los retos. De igual manera esta el Pico Firmware del archivo en C++ que ejecuta el Pico y ademas en NPC_bot está el pico_bridge node que permite hacer el enlace entre lo que trasmite el Pico 2 en C++ y el Python que recibe la Pi5 con el paquete ROS2 Jazzy Jalisco.

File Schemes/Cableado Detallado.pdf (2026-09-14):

# CABLEADO DETALLADO DE PROYECTO MAHORAGA

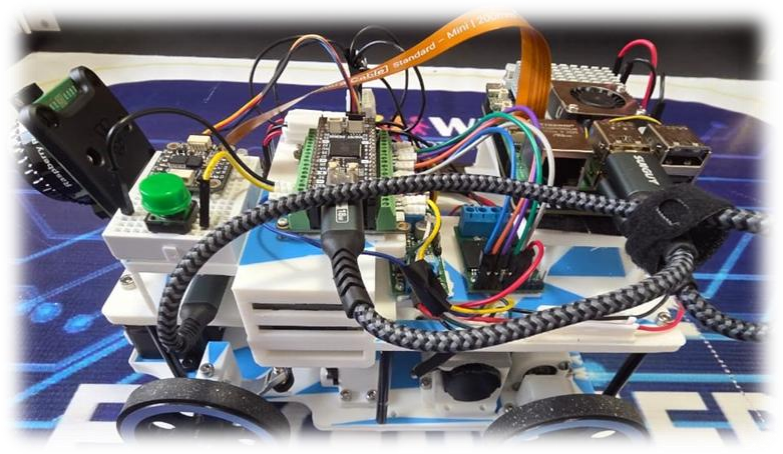
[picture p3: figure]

## Alimentación principal (LiPo 3S)

Desde | Hacia | Cable
LiPo (+) | VNH5019 VIN | Rojo
LiPo (+) | D24V90F5 VIN | Rojo
LiPo (+) | D36V50F5 VIN | Rojo
LiPo (−) | GND común | Negro

## VNH5019 (driver de motor)

Pin VNH5019 | Conectado a | Función
VIN | LiPo (+) | Alimentación de potencia (5.5–24 V)
GND (lado derecho) | GND común | Tierra
OUTA | Motor (+) cable rojo | Salida motor canal A
OUTB | Motor (−) cable negro | Salida motor canal B
INA | Pico GP9 | Control dirección A
INB | Pico GP8 | Control dirección B
PWM | Pico GP12 | Modulación velocidad
ENA / DIAGA | Pico GP10 | Diagnóstico canal A
ENB / DIAGB | Pico GP13 | Diagnóstico canal B
CS | (sin uso)
VDD | D24V90F5 5V | Alimentación lógica

## Encoder del motor

Cable | Color | Conectado a
VCC | Azul | Pico Plus 2 pin 35 (3.3 V)
GND | Verde | Pico Plus 2 pin 3 (GND)
ENCA | Amarillo | Pico Plus 2 GP2
ENCB | Blanco | Pico Plus 2 GP3

## Servo Savox SC-1251MG

Cable servo | Color | Conectado a
Signal | Amarillo | Pico Plus 2 GP15
V+ | Rojo | D36V50F5 VOut (5 V)
GND | Negro | D36V50F5 GND (uno de los 4)

## Bus Qwiic (I²C) Pico → Sensores

## Pico Plus 2 Qwiic conectado a SparkFun Qwiic MultiPort ─► BNO085 (IMU) ─► VL53L4CD #1 (ToF izquierdo) ─► VL53L4CD #2 (ToF derecho)

## Bus USB (RPi 5)

Periférico | Puerto
Pico Plus 2 | USB-A del RPi 5 (cable USB-C 3.1 Gen2 corto, 6 in)
LiDAR STL-27L | USB-A del RPi 5 (vía adaptador CP2102 incluido)

## Bus FPC (cámara)

## Cable FPC 22-pin 0.5 mm → 15-pin 1 mm, 200 mm, conectado del puerto CSI-2 del RPi 5 al

conector de la cámara Global Shutter.

## Alimentación de la lógica (D24V90F5 5V)

Desde | Hacia | Pin RPi
D24V90F5 VOut (5 V) | RPi 5 pin 2 (5V) | GPIO header
D24V90F5 GND | RPi 5 pin 39 (GND) | GPIO header
(GND adicional) | RPi 5 pin 6 (GND) | a GND común

## Botón de inicio

Pin botón | Conectado a
GND | Pico Plus 2 pin 32 (GND)
Signal | Pico Plus 2 pin 28 (GP) con pull-up interno

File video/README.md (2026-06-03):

**En esta carpeta encontraras todos los videos que publicamos ya sea explicativo o videos del carro haciendo el recorrido. Nuestro canal de Youtube es
@NPC2-WRO2026
https://www.youtube.com/@NPC2-WRO2025**

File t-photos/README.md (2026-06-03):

**En esta carpeta encontraras las fotos de cada miembro del equipo que son: 
LEONARDO CARRASQUERO 16 AÑOS
JUAN IGNACIO GONZALEZ 16 AÑOS
VU TUE ANH 16 AÑOS**

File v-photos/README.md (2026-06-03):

**En esta carpeta van a poder ver las fotos del carro y planificaciones de la estructura del carro.**

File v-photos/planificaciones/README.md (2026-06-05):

En esta carpeta encontraras los primeras formas de diseño del carro.

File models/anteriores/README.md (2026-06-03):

**En este carpeta encontraras los modelos que hicimos al principio de la competencia como previamente lo explicamos.**

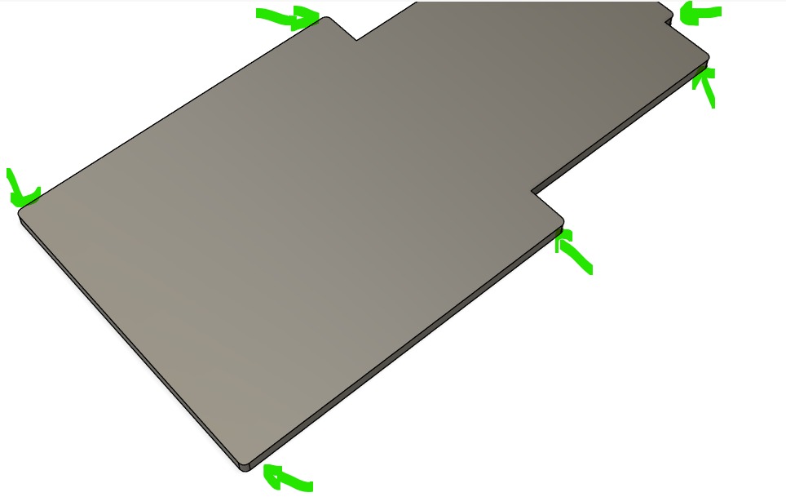
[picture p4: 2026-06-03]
setup of the car and software/Foto Diseño Inicial de Chasis de Abajo.jpeg

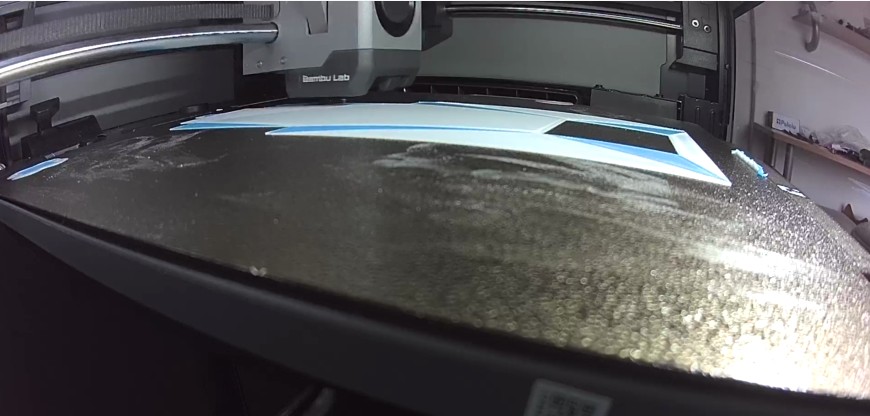
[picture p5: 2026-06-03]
models/anteriores/Chassis Abajo V1.jpg

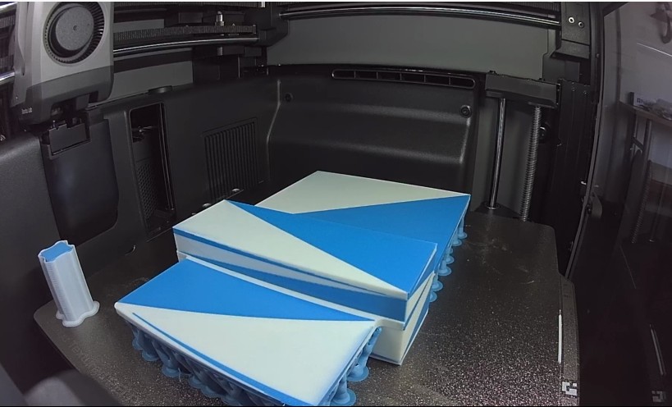
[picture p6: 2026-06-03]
models/anteriores/Chassis de Arriba V1.jpg

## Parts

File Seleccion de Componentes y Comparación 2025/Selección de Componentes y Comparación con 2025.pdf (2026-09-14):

## Selección de Componentes y Evolución de “Proyecto Mahoraga” (WRO 2026) vs “Crazy Diamond” (WRO 2025)

### 1. Experiencia Previa (WRO 2025)

Este es nuestro segundo año en competencias de la WRO Futuros Ingenieros, el año pasado participamos con “Crazy Diamond”, obteniendo una calificación destacada en los 3 eventos regionales que participamos y logrando la 2da puntación más alta de toda la ronda clasificatoria a la Final Nacional de Venezuela, donde obtuvimos el 5to Lugar.

En julio 2025 fuimos al invitacional multinacional en Weifang, China donde logramos el 1er Lugar de la categoría Futuros Ingenieros.

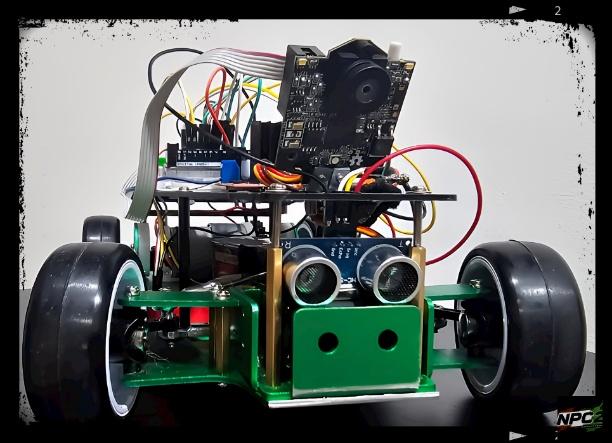
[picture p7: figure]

Lo Que Funcionó Bien

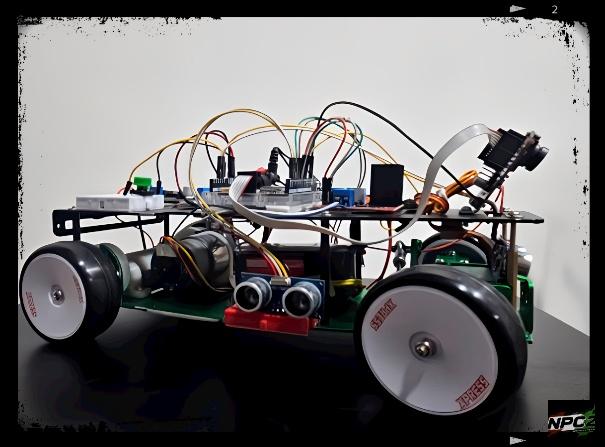
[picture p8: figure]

1. Logramos una elevada tasa de éxito en el Open Challenge. Utilizábamos sensores ultrasónicos para detectar las aperturas y las desviaciones respecto al centro de la pista, con algoritmos simples.
2. El robot era robusto y no presentó inconvenientes técnicos en las competencias.

Los Problemas Que Enfrentamos

1. Tratamos de utilizar otros tipos de sensores de tecnología superior como TOF VL53L0X y MaxBotix HRLV-ShortRange-EZ Sensors, pero no eran confiables por el rebote de la señal dependiendo del ángulo del robot y su menor eficiencia en paredes negras.
2. Conexión intermitente del IMU BNO085 con el Arduino R4 que nos llevó a descartar su uso, lo cual limitó la eficiencia de la estrategia de giros.
3. Logramos una identificación temprana de los pilares de obstáculos, pero solo con los ultrasónicos éramos poco efectivos en realizar las maniobras de evasión. Tuvimos que “Hardcode” parte del código para intentar hacer evasiones, pero era algo muy fijo y no se ajustaba a cambio de condiciones o posicionamiento de pilares.
4. El robot era muy grande, con 18 cms de ancho y casi 28 cms de largo, para transitar canales que podían ser de 40 cms o pilares que de la pared podían dejar un espacio efectivo de 37,5 cms, nos dejaba apenas 19,5 cms (9,75 cms de cada lado) de holgura en condiciones ideales que el vehículo viniera recto.

### 2. Objetivos para WRO 2026

La competencia 2025 fue nuestra primera experiencia, aprendimos muchísimo y el reto era mejorar para el 2026 y alcanzar la Final Internacional.

Aprendimos que:

Nuestra primera experiencia en la competencia de 2025 fue un gran aprendizaje. Aunque el panorama fue retador, nos sirvió para darnos cuenta de lo que realmente necesitábamos para subir de nivel y ponernos como meta clara alcanzar la Final Internacional este 2026.

Estas fueron las lecciones clave que nos dejaron esa primera participación:

- El tiempo es clave: Entendimos que no podíamos perder ni un día. En la temporada pasada empezamos a trabajar en abril, pero para este ciclo nos propusimos arrancar en enero, apenas la WRO oficializó el reto y sus nuevas reglas. Esos tres meses de ventaja hicieron toda la diferencia para planificar con calma.
- Evolución en hardware y software: Ver de cerca las soluciones que llevaron los equipos a la Final Internacional 2025 nos abrió los ojos. Nos dimos cuenta de que, si queríamos ser competitivos, nuestro robot actual no iba a bastar; necesitábamos un salto de calidad drástico tanto en los componentes físicos como en la arquitectura del código.
- Aprender de la comunidad: Pasamos mucho tiempo investigando, analizando videos de competencias previas y, sobre todo, estudiando a fondo repositorios de GitHub de equipos exitosos en 2024 y 2025. Gracias a eso, pudimos estructurar una hoja de ruta súper clara con los cambios técnicos exactos que Proyecto Mahoraga necesitaba para este 2026.

Basándonos en nuestra experiencia de 2025, establecimos objetivos para 2026:

Objetivos Técnicos

1) Tener un robot más pequeño y ágil para tener mayor margen en la evasión de obstáculos.
2) Tener un chasis hecho a la medida de las necesidades y no uno comercial como empleamos en 2025.
3) Incorporar un LiDAR para un mapeo robusto de obstáculos y bordes.
4) Incorporar un IMU para tener un desarrollo más robusto que nos permitiera medir de una mejor manera los ángulos de giro y las desviaciones
5) Un microprocesador más potente para poder tener una fluidez en la transmisión de datos de los sensores y motores.

6) Incorporar un procesador de alta gama como el Raspberry Pi 5 de 16 Gb para garantizar el manejo de las imágenes de la cámara y el LiDAR, al tiempo de centralizar el control del robot.

### 3. Investigación de Soluciones

Mejores Equipos de Final Internacional 2025

Investigamos soluciones de los equipos con los mejores puntajes en la Final Internacional 2025. Hicimos cuadros comparativos de los componentes que utilizaron, así como el tipo de lenguaje de programación.

Analizamos y sacamos conclusiones de la información en los repositorios y los videos en Youtube.

Lo que aprendimos de otros equipos:

- Solo 3 del Top 15 uso soluciones en Lego EV3, pero además lo descartamos porque queríamos trabajar con soluciones más avanzadas.
- El Raspberry Pi y principalmente la versión 5, era el controlador más utilizado entre los equipos de mayor puntaje.
- El Arduino era usado por solo 2 equipos y solo como microcontrolador acompañante. Evidenciando la desventaja con la que trabajamos en 2025. ESP32 y el Raspberry Pico 2 resultaron como los microcontroladores más usados.
- 6 del top 10, utilizaron un LiDAR y tenían estrategias robustas de detección.
- Prácticamente todos los equipos utilizaron un IMU, versiones BNO085 y BNO055.
- Los equipos utilizaron controladores de motores más modernos y avanzados que el L298N que utilizamos en 2025, recomendado solo para experimentos de robótica simple.
| Equipo | | | | | Documentación | ∑ | Github
1. | 6030 - Double-X | 30.0 (30) | 30.0 (37) | 62.0 (63) | 62.0 (49) | 29.3 | 121.3 (79) | https://github.com/ejm22/WRO-FE-XX
2. | 6018 - KMIDS GFM | 30.0 (43) | 30.0 (43) | 62.0 (60) | 62.0 (63) | 29.0 | 121 (103) | https://github.com/Chayanon-Ninyawee/KMIDS-GFM-Future-Engineer-2025
3. | 6001 - STORMS NGR | 30.0 (24) | 30.0 (22) | 62.0 (87) | 62.0 (69) | 29.0 | 121 (91) | https://github.com/MoCsabi/WRO2025-FE-StormsNGR
4. | 6009 - FireOnAllCylinders | 30.0 (41) | 30.0 (44) | 47.0 (65) | 62.0 (73) | 27.3 | 119.3 (114) | https://github.com/kirkhu/WRO2025_FE-Fire-On-All-Cylinders
5. | 6003 - ANTİ | 30.0 (22) | 0.0 (180) | 62.0 (47) | 47.0 (42) | 27.0 | 119 (69) | https://github.com/atakanersoy/WRO2025_FE_ANTi
6. | 6045 - Team LazyGo | 30.0 (45) | 5.0 (14) | 29.0 (53) | 62.0 (110) | 27.0 | 119 (155) | https://github.com/A-N-M-Noor/LazyGo_WRO2025
7. | 6006 - KMW Battlepillars | 30.0 (63) | 30.0 (64) | 62.0 (162) 27.0 (110) | 27.0 | 119 (225) | https://github.com/Battlepillars/Wro
8. | 6042 - SQ-391 | 30.0 (77) | 30.0 (99) | 62.0 (135) 62.0 (99) | 26.0 | 118 (176) | https://github.com/Alhadi1123/SQ-391_WRO_Future_Engineers_2025
9. | 6029 - Ishikawa KOSEN | 30.0 (112) 30.0 (124) | 62.0 (157) 11.0 (38) | 25.7 | 117.7 (269) | https://github.com/UNOsan118/WRO2025_FE_INCT
10. | 6011 - QYZYLORDA Flame | 30.0 (63) | 30.0 (51) | 47.0 (114) 62.0 (120) | 25.0 | 117 (171) | https://github.com/QZOFlameFE/FE2025_1st_repo_ByFlame
11. | 6024 - Greenbotics | 30.0 (45) | 30.0 (52) | 62.0 (75) | 62.0 (61) | 24.0 | 116 (106) | https://github.com/Devansh-awat/greenbotics
12. | 6012 - shahrood RC | 30.0 (41) | 0.0 (180) | 44.0 (120) 62.0 (141) | 24.0 | 116 (182) | https://github.com/ShahroodRC/WRO2025-FE-ShahroodRC
13. | 6058 - X-UniTech | 30.0 (34) | 30.0 (31) | 47.0 (76) | 62.0 (89) | 23.3 | 115.3 (120) | https://github.com/vunxiuxuan/X-UniTech-IPGKS
14. | 6025 - Paraducks | 30.0 (66) | 30.0 (76) | 62.0 (173) 18.0 (46) | 21.7 | 113.7 (239) | https://github.com/DevShah1407/WRO-Paraducks
15. | 6052 - AZE 44 | 30.0 (61) | 30.0 (64) | 8.0 (27) | 62.0 (177) | 20.3 | 112.3 (238) | https://github.com/coolboy19521/AZE44

Partidos
clasificatorios | Partidos finales

- La mayoría de los equipos usaron chasis y piezas hechas en 3D. Aquellos que usaron chasis comerciales hicieron modificaciones importantes y complementaron con piezas impresas en 3D.

Acá anexamos un cuadro comparativo.

Equipo | Cámara | Sensor de Distancia | Controlador de Motores | Lenguaje de Programación | Controlador Principal | Controlador Secundario | IMU | Motor | Servo | Diferencial | Convertidor de Voltaje | Otro | Largo | Acho
LazyGo | Logitech C270 | LiDAR (RPLidar C1) | VNH2SP30 Motor Driver | Python, C++ (ROS2), | Raspberry Pi 5 | ESP32 Microcontroller. ESP-WROOM-32 30/38Pin | BNO055 9‑Axis IMU | 25GA Gear Motors + Encoder | PS1171MG Servo | LEGO Differential (Gen 3) | 5V 20A Buck Converter | | 20 | 10
SQ-391 | Raspberry Pi Camera Module 3 | 4 Ultrasónic o (URM09) | DRV8871 Motor Driver | Python (ROS Noetic), | Raspberry Pi 4 Model B | ESP32-WROOM-32E | BN0085 | Core DC Motor (6 V, 400 RPM) | TowerPro MG996R Servo y Micro Servo Motor SG90 | | XL4005 DC-DC Step-down | PCA9685 Servo Driver HAT
Battlepillars | Raspberry Pi Camera Module 3 Wide | LiDAR (RpLidar S2) | Quicrun WP 1080–G2 | Python | Raspberry Pi 5 | Servo Controller (Adafruit) | SparkFun Optical Tracking Odometry Sensor. Porque el motor no tiene encoder | 23-turn brushed 370-size LaTrax® motor with bullet connectors | Traxxas Waterproof Sub-Micro Servo (model number 2065A | | Pololu 5V Step-down | | 19 | 12,8
KMIDS-GFM | Fish-Eye Lens RPi 5MP IR Camera | LiDAR (RPLidar S2) | DRV8871 Motor Driver | C++ | Raspberry Pi 5 | Raspberry Pi Pico 2 | BNO085 | N20 Motor, 6V 500 RPM | Servo: S0009M | LEGO differential gear system | UPS EP-0136 <br> DC-DC Boost Step-Up | Transistor: N-Channel MOSFET | 24,4 | 12
Ishikawa KOSEN | 2DOF Monocular Camera | LiDAR (STL-19P D500) | RRC Lite Controller | Python (ROS 2) | Raspberry Pi 5 | RRC Lite Controller | BNO055 9‑Axis IMU | DC Geared Motor w/ Encoder | Hiwonder LFD-01 Servo | | Hiwonder RRC Lite Controller | Control Board for LiDAR incluido en el kit del Lidar con el RRC Controler | 19,5 | 15
Double-X | Pi Camera 3 Wide | Basado en Visión (Cámara) | DRV8825 (Stepper driver) | Python y C++ | Raspberry Pi 5 | Arduino Uno R3 | No USA | NEMA 17 Stepper Motor | HS 225BB Servo Motor | | No especificado | | 28,5 | 13,5
Greenbotics | Raspberry Pi Camera Module 3 | ToF (VL53L1X/L 8CX) y Ultrasónic o (URM09) y VL53L8CX | TB6612FNG Dual Motor Driver | Python | Raspberry Pi 5 | | BNO055 IMU | LEGO EV3 Medium Motor, | Servo SG90 | LEGO differential gear system | XY-3606 | Multiplexor I2C (TCA9548A)
StormsNGR | Cámara (Modelo no especificad o) | LiDAR sensor STL-19P, D500 developme nt kit | DRV8871-MK | Python y C | Raspberry Pi 5 4GB | Microcontroller (ESP) NodeMCU-32S | BNO085 | Hiwonder JGB37-520R30-12 | Steering servo Carson CS-3 | Carbon fiber Lego technic axl | XL4015-3D-STDN-PSU | | 27 | 19,7
AZE44 | Raspberry Pi Camera | Yahboom T-mini Plus LiDAR + 1 HC-SR04 | TB6612FNG Dual Motor Driver | Python (ROS 2), | Raspberry Pi 5 | Raspberry Pi Pico W RP2040 | BNO085 | DC Motor con Encoder | Servo Motor TD8120MG | | | | 19,5 | 15
Fire-On-All-Cylinders | SONY IMX477 camera module | 2 HCSR04 Ultrasónic o e Infrarrojo | L293d motor controller | | Nvidia Jetson Orin Nano | Raspberry Pi Pico W RP2040 | BNO055 IMU | | | Lego 62821b Differential Gear | | | 15,1 | 9,27
ANTi | GC2145 2MP Camera | ToF (VL53L1X y VL53L3CX) | DRV8833 | Python (MicroPython), C++ | STM32H747 (Visión) | nRF52832 (Sensores) | LSM6DSOX | Motor DC N20 de 1500 RPM con codificador | servomotor submicro Feetech FS0307 | | SX1308 Voltage Booster LiPo Rider Plus | | 11 | 5,7

### 4. Partes y Piezas Seleccionadas

Basado en el análisis anterior, seleccionamos los componentes que nos podían permitir el mejor desempeño, garantizando la compatibilidad entre ellos, un tamaño adecuado para estar alineada con nuestra estrategia de tener un vehículo más ágil y pequeño. Finalmente, partes y piezas con basta documentación confiable y que hubiera sido usado con éxito en este tipo de tareas, evitando los errores de 2025 que perseguimos mejores sensores ultrasónicos para terminar con los confiables HCSR04.

Categoría | Componente | Modelo / SKU | Cant. | Link
Cómputo | SBC alto nivel | Raspberry Pi 5 — 16 GB RAM | 1 | Adafruit 6125
| Refrigeración | Official Raspberry Pi 5 Active Cooler | 1 | Adafruit 5815
| Base NVMe | Pimoroni NVMe Base PIM699 | 1 | Adafruit 5845
| SSD | Silicon Power 128 GB M.2 NVMe Gen3 | 1 | Amazon
| MicroSD (backup) | Silicon Power 32 GB | 1 | Amazon
| Microcontrolador | Pimoroni Pico Plus 2 (RP2350) PIM724 | 1 | Adafruit 6244
| Adapter terminal | Adafruit Terminal PiCowbell con sockets | 1 | Adafruit 5907
Sensores | LiDAR 360° | LDROBOT STL-27L (25 m) | 1 | DFRobot 2726
| Cámara | Raspberry Pi Global Shutter (IMX296) | 1 | Adafruit 5702
| Lente cámara | CCTV M12 2.8 mm F2.0 1/2.7" | 1 | Amazon
| Cable cámara | FPC 22-pin → 15-pin, 200 mm (RPi 5) | 1 | Adafruit 5818
| ToF láser | Adafruit VL53L4CD STEMMA QT | 2 | Adafruit 5396
| IMU 9-DOF | Adafruit BNO085 STEMMA QT | 1 | Adafruit 4754
| Concentrador I²C | SparkFun Qwiic MultiPort | 1 | SparkFun
| Cable Qwiic | Flexible Qwiic Cable 50 mm | 4 | SparkFun
Actuadores | Motor + encoder | Pololu 34:1 25Dx67L MP 12V + encoder 48 CPR | 1 | Pololu 4864
| Driver de motor | Pololu VNH5019 Motor Driver Carrier | 1 | Pololu 1451
| Servo de dirección | Savox SC-1251MG digital coreless | 1 | Savox
Potencia | Batería | Zeee LiPo 3S 11.1 V 3200 mAh 50C | 1 | Zeee Battery
| Regulador 5V — Lógica | Pololu D24V90F5 (5 V, 9 A) | 1 | Pololu 2866
| Regulador 5V — Servo | Pololu D36V50F5 (5 V, 5.5 A) | 1 | Pololu 4091
Mecánica | Ruedas | 64 mm aluminio + neumático goma | 4 | Amazon
| Eje trasero | KYX Racing Steel Drive Shaft (Tamiya DT04) | 1 | Amazon
| Manguetas Ackermann | KYX Racing Aluminum Steering Knuckles | 2 | Amazon
| Servo saver | Tamiya TT-02 Hi-Torque | 1 | Tamiya.
| Tie rods | M3 ajustables uxcell | 2 | Amazon
| Ejes | Acero inoxidable 5 mm × 100 mm uxcell | 2 | Amazon
Cables | USB-C Pi↔Pico | SUNGUY USB-C 3.1 Gen2 — 6 in y 1 ft | 2 | Amazon
Mecánica 3D | Filamento | PLA Bambu Lab | — | Bambu Lab
| Impresora 3D | Bambu Lab P2S | — | Bambu Lab

### 5. Chasis

Nuestro diseño mecánico es la culminación de dos generaciones de robots: el vehículo construido para la temporada WRO 2025 y el vehículo completamente rediseñado para 2026. La comparación entre ambos es la mejor evidencia del aprendizaje del equipo.

Versión 2026 vs 2025

El robot de 2025 partía de un chasis comercial más voluminoso y pesado. Estas proporciones eran propias de un RC robusta, pero como ya comentamos penalizaban severamente la maniobrabilidad en el espacio de la pista. Para 2026 decidimos abandonar la plataforma comercial y diseñar un chasis personalizado en Fusion 360, imprimirlo en PLA con Bambu Lab P2S, y reducir las dimensiones:

Parámetro | 2025 | 2026
Largo Total | 280 mm | 235 mm
Ancho Total | 180 mm | 14 mm
Distancia entre ejes (L) | 203 mm | 142 mm (-30%)
Distancia entre pivotes (W) | 130 mm | 97 mm (-25%)
Ancho de rueda | 25 mm | 11 mm (−56%)
Tipo de chasis | En Aluminio, modificado del diseño comercial | Hecho a la medida en Impresión 3D, PLA
Peso Total del Robot | 1.400 gramos | 1.100 gramos

Redujimos 4,5 cms de largo y 4 cms de ancho, si bien esto nos dejo menos espacio para trabajar logramos hacer el espacio mas eficiente con la creación de subniveles que permitían duplicar el espacio para componentes no tan altos y generar un compartimiento en el medio del robot para la pila que no estorbara, la mantuviera seguro y además sirviera de subnivel para colocar el Pico 2 Plus arriba nos dio mucha flexibilidad.

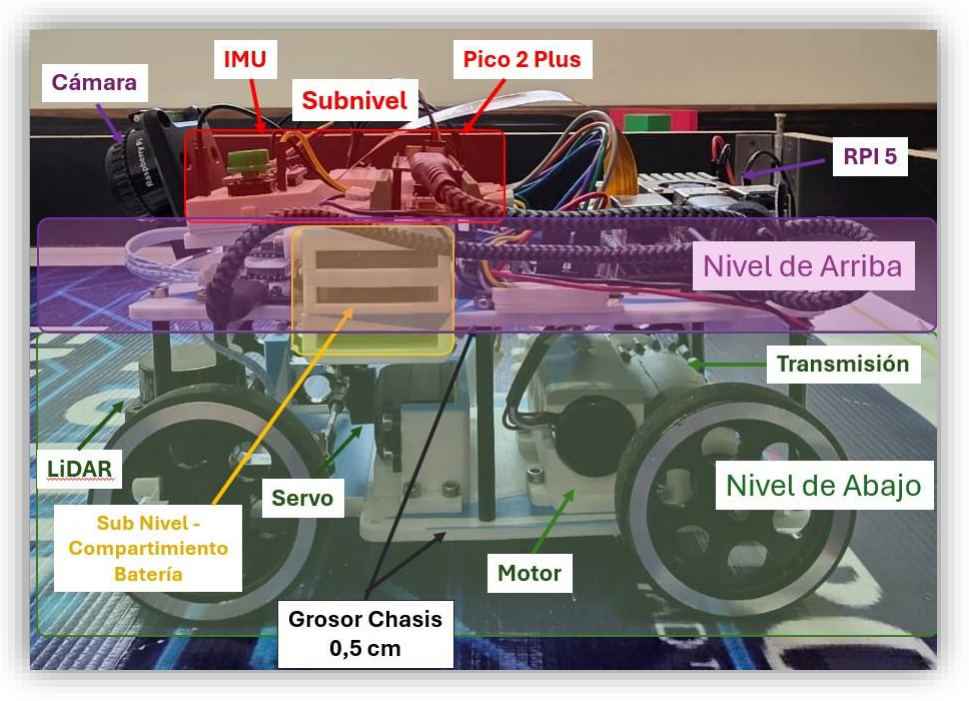
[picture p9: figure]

### 5. Tracción

Selección de Driver de Motor
Uno de los upgrades más importantes para este año fue pasar del obsoleto L298N, más propenso a la caída de voltaje a el VNH5019, que lo supera gracias a su arquitectura basada en MOSFETs que elimina la caída de tensión interna, garantizando la máxima eficiencia hacia los motores, y a su compatibilidad nativa con lógica de 3,3V, lo que permite conectarlo a los pines GPIO de la Raspberry Pi Pico 2 Plus.
Su capacidad de manejar 12A continuos y picos de 30A sirve para absorber las demandas de corriente en arranques y giros bruscos del robot, mientras que su sensor de corriente analógico integrado actúa como una ventaja estratégica para la navegación autónoma, permitiendo al sistema monitorear el esfuerzo mecánico, detectar bloqueos en las ruedas por software y proteger la transmisión antes de que ocurra una falla física.
Especificación Técnica | L298N (2025) | VNH5019 (2026)
Tecnología Interna | Transistores Bipolar (BJT) -Caída de voltaje | MOSFET - Alta eficiencia y baja resistencia
Canales / Motores | 2 motores DC (Puente-H Doble) | 1 motor DC de alta potencia
Voltaje de Operación | 4,8V a 46V | 5,5V a 24V (Soporta picos de hasta 41V)
Corriente Continua | 2A por canal | 12A por canal (Sin disipador adicional)
Corriente de Pico | 3A (Momentáneo) | 30A (Ideal para el arranque de motores pesados)
Voltaje de la Lógica Compatible | 4V a 4,5V requiere conversor de niveles lógicos para aceptar 3,3V | 3,3V y 5V compatible con Pico 2 Plus
Protecciones Integradas | Ninguna (Requiere diodos externos en versiones genéricas) | Voltaje reverso, sobrevoltaje, apagado térmico y cortocircuito
Sensor de Corriente | No posee | Sí (Salida analógica proporcional a la carga del motor)

Selección de Ruedas

Justificación de las ruedas más estrechas (25 mm → 11 mm)

La reducción del ancho de rueda de 25 mm a 11 mm fue una decisión fundamental para reducir el ancho del robot. Esta sola decisión permitía restar 1,4 cms de cada lado, pero no fue una decisión tomada a la ligera, vimos los pro y los contra, porque el performance en 2025 fue bastante bueno.

Lo positivo, ya lo dijimos menos ancho, pero sacrificábamos estabilidad lateral, lo cual no sería relevante por la decisión que tomaríamos después: “Sacrificar velocidad y lograr mejores tiempos por confiabilidad”. A menor velocidad menor temor de inestabilidad en las curvas, además que el robot no sería muy alto y con ruedas pesadas de aluminio y goma, no plástico, garantizábamos un contrapeso ideal.

Aspecto | Ruedas 25 mm (2025) | Ruedas 11 mm (2026)
Estabilidad lateral | Alta | Reducida
Fricción con suelo | Mayor | Menor (menos resistencia al avance)
Ancho total del robot | Penalizado | Reducido (14 mm)
Peso por rueda | Plástico/goma estándar | Aluminio + neumático fino

Decisión: ruedas de 11 mm de aluminio + neumático de goma. La estabilidad lateral se compensa porque las ruedas de aluminio aportan peso bajo en cada esquina del robot, lo que baja el centro de masa y mejora la estabilidad efectiva pese al menor ancho. Adicionalmente, la menor fricción reduce la corriente exigida al motor en línea recta.

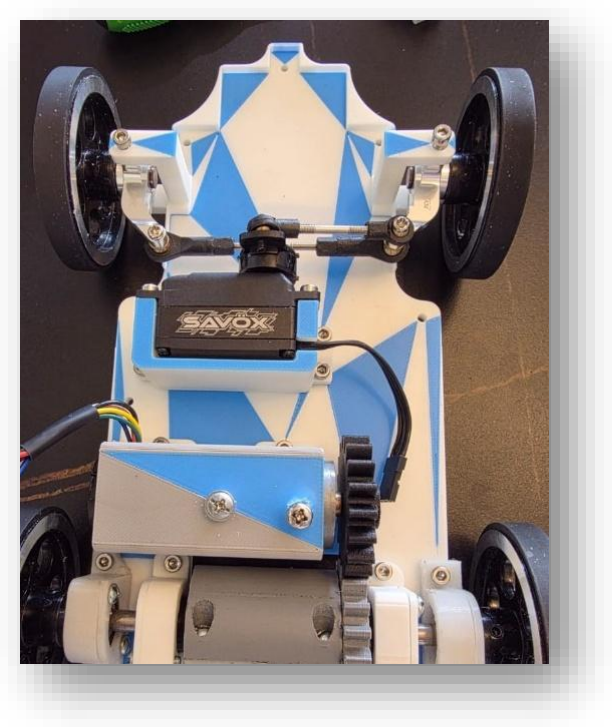
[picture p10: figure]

### 6. Dirección

Ackerman

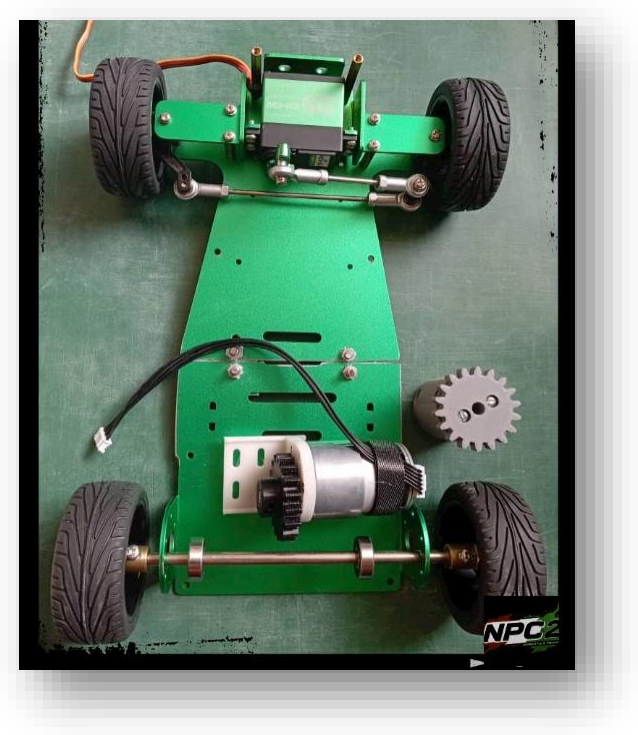
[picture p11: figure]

Competir en Futuros Ingenieros WRO 2026 requiere un vehículo de 4 ruedas con dirección real (no diferencial). El sistema Ackermann es prácticamente obligatorio.

Si las dos ruedas delanteras giraran al mismo ángulo (paralelas), la rueda interna (la del lado interior de la curva) se vería forzada a "arrastrar" o derrapar. Esto ocurre porque, en una curva, la rueda interna recorre un círculo más pequeño que la rueda externa.

Para aplicar la geometría Ackermann no usamos las dimensiones externas del chasis, sino las de los puntos de giro reales. La distancia entre pivotes es menor que el ancho total porque las ruedas tienen grosor y los tornillos sobre los que giran (pivotes / kingpins) están dentro del contorno de las ruedas.

Por eso las decisiones de tamaño del chasis y selección de ruedas y servo ern fundamentales para lograr mejor maniobrabilidad y vencer los obstáculos con mayor holgura.

Comparativo de Giro de Proyecto Mahoraga 2026 vs Crazy Diamond 2025

Parámetro | Crazy Diamond 2025 | Proyecto Mahoraga 2026 | Mejora
Batalla (L) | 203 mm | 142 mm | −30%
Pivotes (W) | 130 mm | 97 mm | −25%
Radio de giro (R) | 306,9 mm | 217,7 mm | -29%
Distancia para 90° | 482,1 mm | 341,90 mm | -29%

Fórmula del radio de giro

La fórmula considera tanto la batalla como la distancia entre pivotes para hacer un giro a 40 grados es:

R = L / tan(δ) + W / 2

R = 142 / tan (40°) + 97 / 2 R = 142 / 0.839 + 48.5
R = 217.7 mm

Cálculo de la distancia recorrida en un giro de 90°

Distancia = (2 × π × R) / 4 Distancia = (2 × π × 217.7) / 4 ≈ 341.9 mm

Proyecto Mahoraga (2026) recorre 14 cm menos por cada giro de 90°, mostrando su mayor agilidad lo cual será fundamental para superar los retos con éxitos de la WRO, dado que:

- El robot responde en un espacio más confinado, dando más margen de error al código de evasión cuando la cámara o LiDAR detecten un pilar.
- El radio de 21,7 cm permite encajar en el área de estacionamiento con maniobras cortas, minimizando el riesgo de que el voladizo trasero golpee los bordes magenta.

Selección del servo: Savox SC-1251MG

El Savox SC-1251MG es un servo avanzado, digital, con una velocidad de 0,07s para girar 60°, con un refresh rate de 240 Hz, lo que lo hace sumamente rápido. Ideal para los retos de la WRO donde necesitamos una alta capacidad de respuesta para girar. Al comparar con el modelo que usamos saltan marcadas diferencias, siendo 68% mas rápido para girar hasta girar 60°, es decir, al Yahbbom le toma 63 ms adicionales girar y el Savox tiene casi 5 veces mayor tasa de refrescamiento. Al ser Coreless y de engranajes de metal lo hace más preciso. La mayor ventaja del Yahboom esta en el torque, que se podía justificar más el año pasado que teníamos un vehículo más grande y pesado, pero con Proyecto Mahoraga los 9.0 kg.cm son más que suficientes.

Característica | Savox SC-1251MG (2026) | Yahboom 20kg (2025)
Par / Torque | 9.0 kg·cm | 20.0 kg·cm
Velocidad @ 6V | 0.07 s/60° | 0.151 s/60°
Tipo de motor | Coreless | Brushed (con núcleo)
Engranajes | Metal duro | Cobre (más blando)
Refresh rate | 240 Hz | 50 Hz
Peso | 44,5 g | 68,2 g
Voltaje | 4,8–6,0 V | 5,0–8,4 V

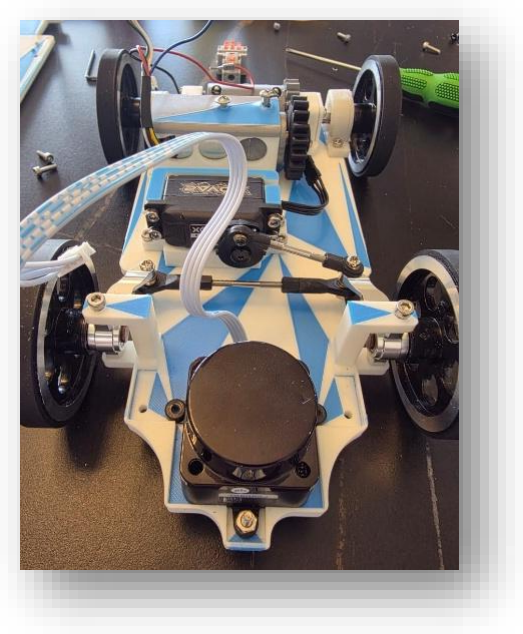
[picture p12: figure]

Posición del servo

En el robot 2025 y en nuestro primer prototipo 2026, el servo estaba montado delante de las ruedas delanteras (configuración tradicional RC). Decidimos cambiar a una configuración donde el servo va detrás de las ruedas delanteras, con el servo saver mirando hacia adelante, liberando espacio así para poder ubicar el LiDAR en la parte delantera e inferior del vehículo.

El servo está fijado al chasis a través de un soporte hecho a la medida en impresión 3D, para garantizar la altura ideal de las barras conectadas a las manguetas. El soporto requirió de varias iteraciones en el diseño, hasta la última que incluyó pestañas para fijarlo al chasis con tornillos de precisión.

### 7. Resumen de Diseño y Comparación con 2025

Subsistema | Componente final | Razón principal
Chasis | PLA impreso 3D, 2 pisos + subnivel | Eficiencia espacio + iterabilidad
Tracción | Pololu 34:1 MP 12V + encoder 48 CPR | Par alto + control fino
Odometría | 2006 ticks/metro (calibrado) | Mediciones empíricas
Driver | VNH5019 | Margen amplio voltaje + sensado corriente
Diferencial | Impreso 3D propio + eje KYX acero | Geometría a medida + dureza
Dirección | Ackermann, Savox SC-1251MG detrás de ruedas | Digital coreless + libera espacio LiDAR
LiDAR | Primer piso adelantado | Altura óptima para paredes 10 cm
Manguetas | KYX Racing aluminio (DT04) | Resistencia cargas laterales
Servo saver | Tamiya TT-02 | Protege servo, sin holgura
Tie rods | M3 ajustables uxcell | Ajuste fino de convergencia
Ruedas | 64 × 11 mm aluminio + goma | Menos fricción + menor ancho total

Logros cuantitativos de Proyecto Mahoraga respecto a Crazy Diamond

−29% radio de giro (306.9 → 217.7 mm)

- −29% distancia recorrida en giro de 90° (482,1 → 341,9 mm)
- −30% batalla, −25% pivotes
- −56% ancho de rueda (25 → 11 mm)
- 126 mm de alto total por eliminación del tercer piso
- 180° de visión LiDAR frontal limpia (en vez de utilizar Ultrasónicos)
- 2.006 ticks/metro de resolución calibrada para odometría

### 8. Baterías y Reguladores

Batería: Zeee LiPo 3S 11.1 V 3200 mAh 50C

Parámetro | Valor
Tipo de química | LiPo (polímero de litio)
Configuración | 3S (3 celdas en serie)

Parámetro | Valor
Voltaje nominal | 11,1 V
Voltaje plenamente cargada | 12,6 V (4,2 V × 3)
Voltaje fin de descarga útil | ~9,0 V (3,0 V × 3)
Capacidad | 3000 mAh
Tasa de descarga máxima | 50C
Conector | Deans T

El uso de la batería de 11,1V era fundamental para poder pasar de un motor de 6V a uno de 12V, garantizando un mejor performance y precisión del vehículo. Usar una pila de 3.000 mAh nos permitía no necesitar una pila de gran tamaño y mayor peso y por los cálculos detallados incluidos en el Readme nos da la suficiente autonomía para potenciar el robot por cerca de 1 hora con holgura.

Reguladores 5V

Una decisión central del diseño eléctrico es usar dos reguladores 5V independientes en lugar de uno solo:

¿Por qué dos reguladores 5V y no uno solo?

Esta es la decisión más importante del diseño de potencia. Los fundamentos técnicos son:

### 1. Aislamiento de transitorios

El servo digital coreless Savox SC-1251MG tiene picos de corriente de hasta 3.5 A durante stalls o cambios bruscos de posición (giros de 90° en pocas decenas de milisegundos). Estos picos son transitorios inductivos que generan caídas momentáneas de tensión en el riel que los alimenta.

Si el servo compartiera riel con el Raspberry Pi 5, una caída de tensión de 200-400 mV durante un giro brusco podría:

- Resetear el RPi 5 (sensible a bajos voltajes)
- Generar errores I²C en el bus de sensores
- Corromper datos en mitad de un escaneo del LiDAR

Al darle al servo su propio regulador, los transitorios quedan contenidos en su riel y no contaminan la lógica.

### 2. Holgura de corriente diferenciada

Bus | Corriente continua | Corriente pico | Regulador
Bus servo | ~0.5 A | 3.5 A | D36V50F5 (5.5 A) → margen 57%
Bus lógica | ~2.2 A | 4.0 A | D24V90F5 (9 A) →

Bus | Corriente continua | Corriente pico | Regulador
| | | margen 125%

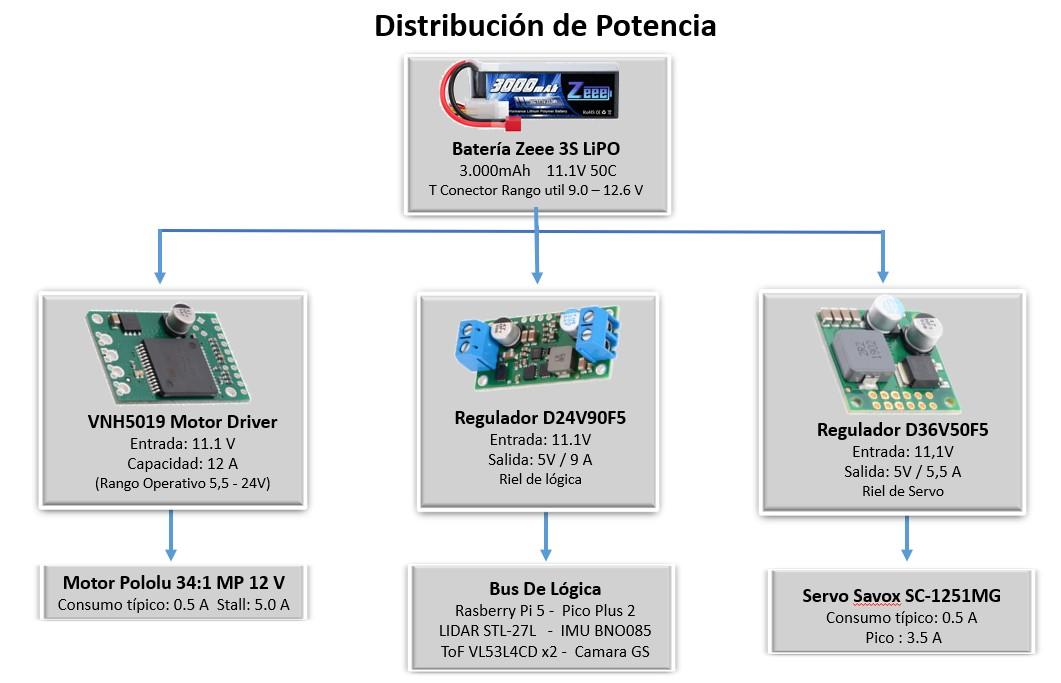
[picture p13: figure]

Si hubiéramos usado un solo regulador, habríamos necesitado al menos 9 A continuos (suma de ambos) más margen, lo que nos llevaría a solo usar el D24V90F5, pero entonces los transitorios del servo seguirían contaminando la lógica.
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

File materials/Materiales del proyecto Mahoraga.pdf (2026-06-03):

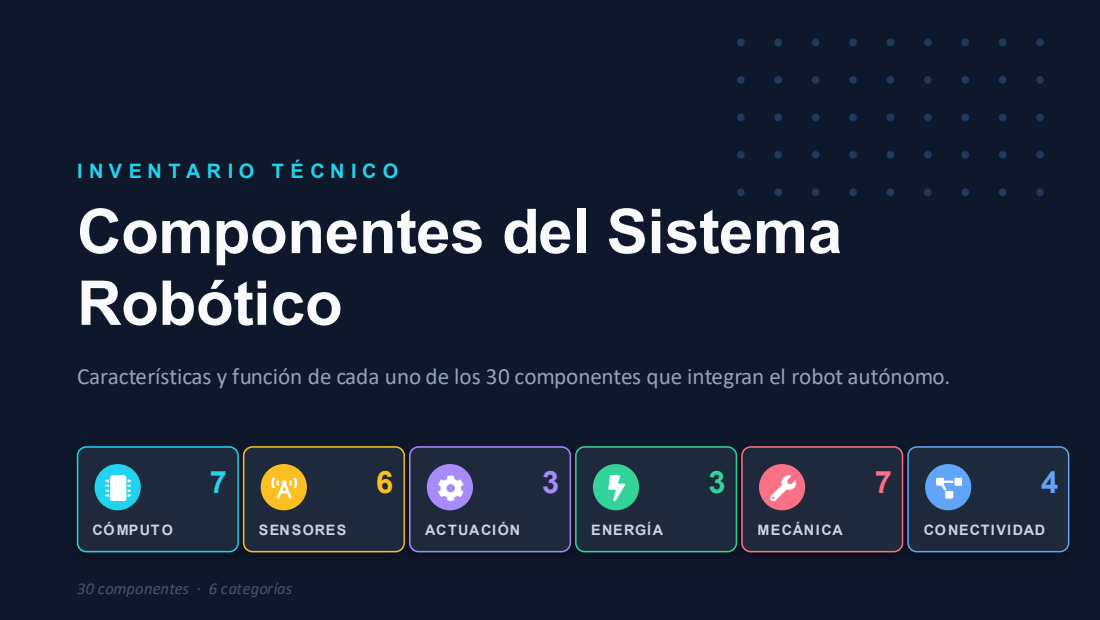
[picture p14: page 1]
I N V E N T A R I O T É C N I C O Componentes del Sistema Robótico; CÓ MPUT O; SENSORES; ACTUACIÓN; ENERGÍA; MECÁNICA; CO NECTIVIDAD; 30 componentes · 6 categorías

Características y función de cada uno de los 30 componentes que integran el robot autónomo.

CÓ MPUTO | 01 / 30

# Raspberry Pi 5 (16 GB RAM)

Raspberry Pi 5 — 16 GB RAM

CARACT ERÍSTICAS

SoC Broadcom BCM2712: 4 núcleos Cortex-A76 a 2,4 GHz

16 GB de RAM LPDDR4X y GPU VideoCore VII

PCIe 2.0, 2× USB 3.0, Gigabit Ethernet, Wi-Fi y Bluetooth

Chip de E/S dedicado RP1 para periféricos

FUNC IÓN

Es la computadora principal y el «cerebro» del robot. Ejecuta el sistema operativo, la visión por computadora y los algoritmos de navegación de alto nivel, integrando los datos de todos los sensores para tomar decisiones.

Sistema Robótico Autónomo · Inventario de Componentes

CÓ MPUTO | 02 / 30

# Raspberry Pi 5 Active Cooler

Official Raspberry Pi 5 Active Cooler

CARACT ERÍSTICAS

Disipador de aluminio con ventilador controlado por PWM

Clip de montaje rápido directamente sobre el SoC

Almohadilla térmica preaplicada y conector dedicado

FUNC IÓN

Mantiene fría la CPU bajo carga para evitar el «throttling» térmico. Permite que la Pi 5 sostenga su frecuencia máxima durante tareas intensivas como el procesamiento de visión.

CÓ MPUTO | 03 / 30

# Base NVMe Pimoroni (PIM699)

Pimoroni NVMe Base for Raspberry Pi 5 — PIM699

CARACT ERÍSTICAS

Placa inferior que expone el conector PCIe (FPC) de la Pi 5

Admite SSD M.2 en formatos 2230, 2242, 2260 y 2280

Conserva un formato compacto bajo la placa; incluye cable y tornillería

FUNC IÓN

Habilita la conexión de un SSD NVMe a la Raspberry Pi 5, permitiendo arranque y almacenamiento de alta velocidad muy superiores a una tarjeta microSD.

CÓ MPUTO | 04 / 30

# SSD NVMe Silicon Power 128 GB

Silicon Power 128 GB NVMe M.2 PCIe Gen3x4 2280 (SP128GBP34A60M28)

CARACT ERÍSTICAS

Formato M.2 2280, interfaz PCIe Gen3 x4

Capacidad de 128 GB con memoria NAND 3D

Lectura secuencial de hasta ~2.100 MB/s y bajo consumo

FUNC IÓN

Almacenamiento principal de alta velocidad para el sistema operativo, registros (logs), mapas y conjuntos de datos. Acelera el arranque y la lectura/escritura frente a la tarjeta SD.

CÓ MPUTO | 05 / 30

# MicroSD Silicon Power 32 GB

Silicon Power 32 GB 3D NAND High Speed MicroSD con adaptador

CARACT ERÍSTICAS

Capacidad de 32 GB con memoria NAND 3D de alta velocidad

Incluye adaptador a tamaño SD estándar

FUNC IÓN

Sirve como medio de arranque o almacenamiento secundario y de respaldo. Es útil para grabar la imagen inicial del sistema o transferir datos al robot.

CÓ MPUTO | 06 / 30

# Pimoroni Pico Plus 2 (RP2350)

Pimoroni Pico Plus 2 — RP2350 Dev Board — PIM724

CARACT ERÍSTICAS

Microcontrolador RP2350 (doble núcleo Cortex-M33 / RISC-V)

4 MB de flash y 8 MB de PSRAM; USB-C

Conector Qwiic/STEMMA QT y pines compatibles con Pico

FUNC IÓN

Coprocesador de tiempo real para tareas de bajo nivel: lectura de encoders, generación de PWM y control directo de motores y servo, liberando a la Pi de operaciones con temporización estricta.

CÓ MPUTO | 07 / 30

# Adafruit Terminal PiCowbell (Pico)

Adafruit Terminal PiCowbell for Pico — Reset + STEMMA QT

CARACT ERÍSTICAS

Placa adaptadora para Pico con borneras presoldadas

Botón de reset y conector STEMMA QT/Qwiic

Acceso a todos los GPIO sin necesidad de soldar

FUNC IÓN

Facilita un cableado robusto de sensores y actuadores al Pico mediante borneras atornillables. Ideal para prototipos y conexiones de campo que deben resistir vibración.

SENSORES | 08 / 30

# LiDAR LDROBOT STL-27L

LDROBOT STL-27L (LiDAR 2D 360°)

CARACT ERÍSTICAS

LiDAR 2D con escaneo de 360°

Alcance de ~0,03 a 25 m; láser clase 1 (seguro)

Hasta ~21.600 puntos/s; frecuencia de 6–13 Hz; interfaz UART

FUNC IÓN

Escanea el entorno en 360° para mapear y detectar obstáculos. Provee los datos de distancia necesarios para SLAM, localización y evasión de colisiones.

SENSORES | 09 / 30

# Raspberry Pi Global Shutter Camera

Raspberry Pi Global Shutter Camera

CARACT ERÍSTICAS

Sensor Sony IMX296 de 1,58 MP con obturador global

Montura C/CS (y M12 con adaptador) para lentes intercambiables

Conexión por interfaz CSI-2

FUNC IÓN

Captura imágenes sin distorsión por movimiento («rolling shutter»). Es clave para la visión en marcha: seguimiento de líneas u objetos y odometría visual a velocidad.

SENSORES | 10 / 30

# Lente CCTV M12 2.8 mm (F2.0)

Lente CCTV 2,8 mm M12, F2.0, formato 1/2.7", 2 MP

CARACT ERÍSTICAS

Distancia focal de 2,8 mm (gran angular)

Montura M12 y apertura F2.0

Formato 1/2.7" y resolución de 2 MP

FUNC IÓN

Lente intercambiable que enfoca la escena sobre el sensor de la cámara. Su focal corta ofrece un campo de visión amplio, muy útil para navegación y percepción cercana.

SENSORES | 11 / 30

# Cable FPC Cámara RPi 5 (22→15 pin)

Raspberry Pi 5 FPC Camera Cable — 22-pin 0,5 mm a 15-pin 1 mm — 200 mm

CARACT ERÍSTICAS

Cable plano flexible (FPC) de 200 mm

Adapta 22 pines de 0,5 mm (Pi 5) a 15 pines de 1 mm (cámara estándar)

FUNC IÓN

Conecta la cámara al puerto CSI de la Raspberry Pi 5, cuyo conector cambió de tamaño. Transmite la señal de video desde el sensor hacia la computadora.

SENSORES | 12 / 30

# Sensor ToF Adafruit VL53L4CD

Adafruit VL53L4CD Time of Flight Distance Sensor — STEMMA QT/Qwiic

CARACT ERÍSTICAS

Sensor láser de distancia por Tiempo de Vuelo (ToF)

Rango de medición de ~1 a 1.300 mm

Interfaz I2C con conector STEMMA QT/Qwiic; muy compacto

FUNC IÓN

Mide distancias puntuales de corto alcance con gran precisión. Complementa al LiDAR para detectar obstáculos cercanos o medir proximidad y altura.

SENSORES | 13 / 30

# IMU 9-DOF Adafruit BNO085

Adafruit 9-DOF Orientation IMU Fusion Breakout — BNO085

CARACT ERÍSTICAS

Unidad inercial 9-DOF: acelerómetro, giroscopio y magnetómetro

Fusión de sensores integrada en el chip (salida de orientación)

Interfaz I2C/Qwiic con cuaterniones listos para usar

FUNC IÓN

Entrega la orientación y el movimiento del robot (inclinación, giro y rumbo). Es esencial para la estabilización, la odometría y para mantener la dirección de marcha.

ACTUACIÓ N | 14 / 30

# Motorreductor 34:1 25D 12V c/ Encoder

34:1 Metal Gearmotor 25Dx67L mm MP 12V con encoder 48 CPR

CARACT ERÍSTICAS

Motor DC con caja reductora metálica de relación 34:1

Cuerpo de 25 mm de diámetro, 67 mm de largo, 12 V

Encoder en cuadratura de 48 CPR en el eje del motor

FUNC IÓN

Proporciona la tracción del robot. La reducción aumenta el par y el encoder permite medir velocidad y distancia recorrida para el control en lazo cerrado.

ACTUACIÓ N | 15 / 30

# Driver de Motor VNH5019

VNH5019 Motor Driver Carrier (Pololu)

CARACT ERÍSTICAS

Puente H de potencia para un motor DC

Tensión de 5,5 a 24 V; ~12 A continuos (30 A pico)

Control por PWM/dirección, con protección térmica y de sobrecorriente

FUNC IÓN

Etapa de potencia que controla el motor de tracción: regula la velocidad y el sentido de giro a partir de las señales lógicas del microcontrolador.

ACTUACIÓ N | 16 / 30

# Servo Savox SC-1251MG+

Savox SC-1251MG+ Coreless Motor, Metal Gear (servo digital)

CARACT ERÍSTICAS

Servo digital de perfil bajo con motor «coreless»

Engranajes metálicos para mayor durabilidad

Par de ~9 kg·cm y alta velocidad (~0,09 s/60°)

FUNC IÓN

Acciona la dirección («steering») del robot, posicionando las ruedas delanteras con precisión y rapidez para seguir la trayectoria comandada.

ENERGÍA | 17 / 30

# Regulador 5V 5.5A (D36V50F5)

Step-Down Voltage Regulator 5V 5,5A — D36V50F5 (Pololu)

CARACT ERÍSTICAS

Convertidor reductor (buck) de alta eficiencia

Entrada amplia (hasta ~50 V) y salida fija de 5 V

Corriente de salida de ~5,5 A

FUNC IÓN

Convierte el voltaje de la batería a 5 V estables para alimentar la electrónica de control y los sensores de menor consumo.

ENERGÍA | 18 / 30

# Regulador 5V 9A (D24V90F5)

Pololu 5V 9A Step-Down Voltage Regulator — D24V90F5

CARACT ERÍSTICAS

Convertidor reductor (buck) de alta corriente

Salida de 5 V con hasta ~9 A

Alta eficiencia y baja disipación de calor

FUNC IÓN

Suministra 5 V con corriente suficiente para la Raspberry Pi 5 y los periféricos exigentes (cámara, SSD, LiDAR) sin que se produzcan caídas de tensión.

ENERGÍA | 19 / 30

# Batería LiPo 3S 11.1V 3200 mAh

Batería LiPo 3S (11,1 V) — 3200 mAh, 50C

CARACT ERÍSTICAS

Batería de polímero de litio de 3 celdas (11,1 V nominal)

Capacidad de 3200 mAh y descarga de 50C

Conector tipo Deans/T

FUNC IÓN

Es la fuente de energía principal del robot. Alimenta directamente los motores y el servo y, a través de los reguladores, toda la electrónica.

MECÁNICA | 20 / 30

# Rueda Metálica 64 mm

64 mm Metal Drive Wheel, cubo 6 mm, neumático de caucho

CARACT ERÍSTICAS

Rueda de aluminio de 64 mm de diámetro

Cubo central de 6 mm para el eje

Neumático de caucho para tracción

FUNC IÓN

Transmite la tracción al suelo y aporta agarre. El neumático de goma mejora la adherencia y absorbe pequeñas irregularidades del terreno.

CO NECTIVIDAD | 21 / 30

# SparkFun Qwiic MultiPort

SparkFun Qwiic MultiPort

CARACT ERÍSTICAS

Hub Qwiic/STEMMA QT para el bus I2C

Varios conectores en paralelo, sin soldadura

Comparte el bus de datos I2C y la alimentación

FUNC IÓN

Permite conectar varios sensores I2C (IMU, ToF, etc.) al mismo bus de forma ordenada y sin soldar, simplificando el cableado del robot.

CO NECTIVIDAD | 22 / 30

# Cable Qwiic Flexible 50 mm

Flexible Qwiic Cable — 50 mm

CARACT ERÍSTICAS

Cable de 4 conductores (SDA, SCL, 3V3, GND)

Conector Qwiic/JST-SH; longitud de 50 mm

Conexión con polaridad garantizada (plug-and-play)

FUNC IÓN

Interconecta los módulos Qwiic (sensores y hub) llevando datos I2C y alimentación, sin riesgo de invertir la polaridad y sin soldaduras.

CO NECTIVIDAD | 23 / 30

# Cable USB-C 10 Gbps (15 cm)

SUNGUY 10Gbps USB-C, 6 in, 3A, USB 3.1 Gen2

CARACT ERÍSTICAS

USB-C a USB-C, USB 3.1 Gen2 (10 Gbps)

Soporta hasta 3 A de carga; blindado

Longitud corta de ~15 cm

FUNC IÓN

Conexión corta de datos de alta velocidad (por ejemplo, un dispositivo o cámara hacia la Pi) y/o carga, minimizando la longitud y las pérdidas dentro del chasis.

CO NECTIVIDAD | 24 / 30

# Cable USB-C 10 Gbps (30 cm)

SUNGUY 10Gbps USB-C, 1 ft, 3A, USB 3.1 Gen2

CARACT ERÍSTICAS

USB-C a USB-C, USB 3.1 Gen2 (10 Gbps)

Soporta hasta 3 A; longitud de ~30 cm

FUNC IÓN

Cumple la misma función que el cable corto, pero con mayor longitud, para enlazar componentes algo más separados dentro del robot a alta velocidad.

MECÁNICA | 25 / 30

# Eje de Transmisión KYX (Tamiya DT04)

KYX Racing Hard Steel Freewheel Axle / Front Drive Shaft — Tamiya DT04

CARACT ERÍSTICAS

Eje/semieje de transmisión en acero endurecido

Repuesto «upgrade» para chasis RC 1/10 Tamiya DT-04

Mayor resistencia que la pieza plástica original

FUNC IÓN

Transmite el par desde la transmisión hacia las ruedas. La versión en acero soporta mejor los esfuerzos mecánicos del robot que el plástico original.

MECÁNICA | 26 / 30

# Varilla Inox 304 Ø5 × 100 mm

uxcell 5 mm × 100 mm 304 Stainless Steel Solid Round Rod (10 pcs)

CARACT ERÍSTICAS

Varilla maciza redonda de acero inoxidable 304

Diámetro de 5 mm y longitud de 100 mm

Resistente a la corrosión

FUNC IÓN

Elemento estructural o eje para soportes, ejes secundarios o guías mecánicas dentro del chasis del robot.

MECÁNICA | 27 / 30

# Terminales Rótula M3 (Tie Rod)

uxcell M3 3.0×L15mm Lever Steering Linkage Tie Rod End Ball Head (10 pcs)

CARACT ERÍSTICAS

Extremos de varilla con rótula (ball end)

Rosca M3 y longitud de ~15 mm

Diseñados para articulaciones de dirección RC

FUNC IÓN

Forman las articulaciones de los tirantes de dirección, permitiendo un movimiento angular suave entre el servo y las manguetas de las ruedas.

MECÁNICA | 28 / 30

# Conectores Pushrod M3 × 30 mm

uxcell M3×30mm Pushrod Connector Stainless Steel Rod Linkage (10 pcs)

CARACT ERÍSTICAS

Conectores de varilla («pushrod») en acero inoxidable

Rosca M3 y longitud de 30 mm

Fijación mediante tornillo prisionero

FUNC IÓN

Unen y permiten ajustar la longitud de los varillajes que transmiten el movimiento del servo a la dirección, facilitando la calibración de la geometría.

MECÁNICA | 29 / 30

# Servo Saver Tamiya TT-02 (Horn Alu)

Tamiya TT-02 Hi-Torque Servo Saver Set w/ Aluminum Horn (TAM54799)

CARACT ERÍSTICAS

Conjunto «servo saver» de alto par para Tamiya TT-02

Horn (brazo) de aluminio

Resorte amortiguador integrado

FUNC IÓN

Acopla el servo a la dirección y absorbe los impactos, protegiendo los engranajes del servo ante golpes recibidos en las ruedas delanteras.

MECÁNICA | 30 / 30

# Manguetas de Dirección KYX (DT04)

KYX Racing Aluminum Front Steering Knuckles — Tamiya DT04

CARACT ERÍSTICAS

Manguetas («steering knuckles») delanteras de aluminio

Repuesto «upgrade» para Tamiya DT-04

Mayor rigidez que las piezas plásticas

FUNC IÓN

Sostienen las ruedas delanteras y pivotan para dirigir el robot. El aluminio aporta precisión y durabilidad a la geometría de la dirección.

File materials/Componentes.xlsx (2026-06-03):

Componente | Site 1 | Site 2
Raspberry Pi 5 - 16 GB RAM | https://www.adafruit.com/product/6125
Official Raspberry Pi 5 Active Cooler | https://www.adafruit.com/product/5815
Pimoroni NVMe Base for Raspberry Pi 5 - PIM699 | https://www.adafruit.com/product/5845 | https://learn.pimoroni.com/article/getting-started-with-nvme-base
Silicon Power 128GB NVMe M.2 PCIe Gen3x4 2280 SSD (SP128GBP34A60M28) | https://www.amazon.com/Silicon-Power-128GB-P34A60-SP128GBP34A60M28/dp/B09HMWH1DG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
Silicon Power 32GB 3D NAND High Speed MicroSD Card with Adapter | amazon.com/Silicon-Power-Speed-MicroSD-Adapter/dp/B07Q384TPK/ref=sr_1_3?crid=PM7QTJRUY08Y&dib=eyJ2IjoiMSJ9.VsWVPTPqAmwdCz9ETQ3NHTE5yPE0U2Tv5crqaEhfF39P83v4aEZ3ppvjayAVPN8MmK4sQ4RUPk14Wy4-jxpsuwVyzeD1uPd9jK1qoHYS_ibjarcbgSvl0u-BMUQaOmcAoAZ24f_knNpan8vas_Dn3VZ2LGNU5OQJeSUffGxMdpReUQjoC5RcTYml0FGWoE9FA79eCyxEdeKH-JbWtk3gUnwz2tNpXqckgjHurZEoWeQyAz7pkem1I5pCkFy-8H6X.jvr0FmZHtf_im0Oftu-y2m3EuzKBR2LT6aEzzjkl5rE&dib_tag=se&keywords=Silicon+Power+32GB+3D+NAND+High+Speed+MicroSD+Card+with+Adapter&nsdOptOutParam=true&qid=1779392865&s=electronics&sprefix=silicon+power+32gb+3d+nand+high+speed+microsd+card+with+adapter%2Celectronics%2C190&sr=1-3
Pimoroni Pico Plus 2 - RP2350 Dev Board with Pico Shape and Pins - PIM724 | https://www.adafruit.com/product/6244 | https://shop.pimoroni.com/products/pimoroni-pico-plus-2?variant=42092668289107
Adafruit Terminal PiCowbell for Pico with Pre-Soldered Sockets - Reset Button & STEMMA QT | https://www.adafruit.com/product/5907
LDROBOT STL-27L | https://www.dfrobot.com/product-2726.html | https://github.com/May-DFRobot/DFRobot/blob/master/SEN0589_Datasheet.pdf
Raspberry Pi Global Shutter Camera | https://www.adafruit.com/product/5702
1080P CCTV Lens 2.8mm 3.6mm 6mm M12 Mount 2MP Aperture F2.0 1/2.7 Format for Surveillance Camera(2.8MM) | https://www.amazon.com/1080P-Aperture-Format-Surveillance-Camera/dp/B0DBJ3WY45?nsdOptOutParam=true
Raspberry Pi 5 FPC Camera Cable - 22-pin 0.5mm to 15-pin 1mm - 200mm long | https://www.adafruit.com/product/5818
Adafruit VL53L4CD Time of Flight Distance Sensor - ~1 to 1300mm - STEMMA QT / Qwiic | https://www.adafruit.com/product/5396 | https://www.st.com/en/imaging-and-photonics-solutions/vl53l4cd.html
Adafruit 9-DOF Orientation IMU Fusion Breakout - BNO085 (BNO080) - STEMMA QT / Qwiic | https://www.adafruit.com/product/4754 | https://docs.circuitpython.org/projects/bno08x/en/latest/
34:1 Metal Gearmotor 25Dx67L mm MP 12V with 48 CPR Encoder | https://www.pololu.com/product/4864 | https://www.pololu.com/product/4864/resources
VNH5019 Motor Driver Carrier | https://www.pololu.com/product/1451 | https://www.pololu.com/product/1451/resources
Savox SC-1251MG Be Coreless Motor Metal Gear | https://savox-servo.com/en/product/SC-1251MGplus/savox-servo-sc-1251mg-digital-coreless-motor-metal-gear
5V, 5.5A Step-Down Voltage Regulator D36V50F5 | https://www.pololu.com/product/4091 | https://www.pololu.com/product/4091/resources
Pololu 5V, 9A Step-Down Voltage Regulator D24V90F5 | https://www.pololu.com/product/2866 | https://www.pololu.com/product/2866/resources
Batería: LiPo 3S (11.1V) - 3200mAh | https://zeeebattery.com/collections/zeee-3s-lipo-battery/products/zeee-3s-lipo-battery-3200mah-11-1v-50c-deans-t | https://www.amazon.com/Zeee-3200mAh-11-1V-50C-Helic%C3%B3ptero/dp/B0869833F9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
64mm Metal Drive Wheel Inner Dia 6mm Aluminum Master Wheels Rubber Tires for Smart Robot Chassis Car 1Pc | https://www.amazon.com/accionamiento-Di%C3%A1metro-maestras-Neum%C3%A1ticos-inteligente/dp/B0FLX9WQBH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
SparkFun Qwiic MultiPort | https://www.sparkfun.com/sparkfun-qwiic-multiport.html
Flexible Qwiic Cable - 50mm | https://www.sparkfun.com/flexible-qwiic-cable-50mm.html
SUNGUY 10Gbps Android Auto USB Cable 6 inch, 3A USB C 3.1 Gen2 Cable Data Transfer, USB C | https://www.amazon.com/SUNGUY-Android-Transfer-Charging-Samsung/dp/B0CP29QP99?nsdOptOutParam=true
SUNGUY 10Gbps Android Auto USB Cable 1FT, 3A USB C 3.1 Gen2 Cable Data Transfer, USB C | https://www.amazon.com/SUNGUY-Android-Charging-Compatible-External/dp/B0B28ZCV2Y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
KYX Racing Hard Steel Freewheel Axle Front Drive Shaft Upgrades Parts Accessories for 1/10 Rc Crawler Tamiya DT04 | https://www.amazon.com/KYX-Freewheel-Upgrades-Accessories-Crawler/dp/B0FC2F5BGC?nsdOptOutParam=true
uxcell 5mm x 100mm 304 Stainless Steel Solid Round Rod for DIY Craft - 10pcs | https://www.amazon.com/s
uxcell 10 PCS M3 3.0xL15mm Lever Steering Linkage Tie Rod End Ball Head End for RC Helicopter | https://www.amazon.com/uxcell-3-0xL15mm-Steering-Linkage-Helicopter/dp/B07Q2XLP42?nsdOptOutParam=true
uxcell M3x30mm Pushrod Connector Stainless Steel Rod Linkage,for RC Boat,Car,Airplane,Helicopter,10pcs | https://www.amazon.com/uxcell-Connector-Stainless-Airplane-Helicopter/dp/B07MJBJCY6?nsdOptOutParam=true
Tamiya TT-02 Hi-Torque Servo Saver Set w/Aluminum Horn TAM54799 Electric Car/Truck Option Parts | https://www.amazon.com/Tamiya-54799-OP1799-Hi-Torque-Aluminum/dp/B07CXMQLCM?nsdOptOutParam=true
KYX Racing Aluminum Front Steering Knuckles Upgrades Parts Accessories for 1/10 Rc Crawler Tamiya DT04 | https://www.amazon.com/KYX-Aluminum-Steering-Knuckles-Accessories/dp/B0FC2CG8JW?nsdOptOutParam=true

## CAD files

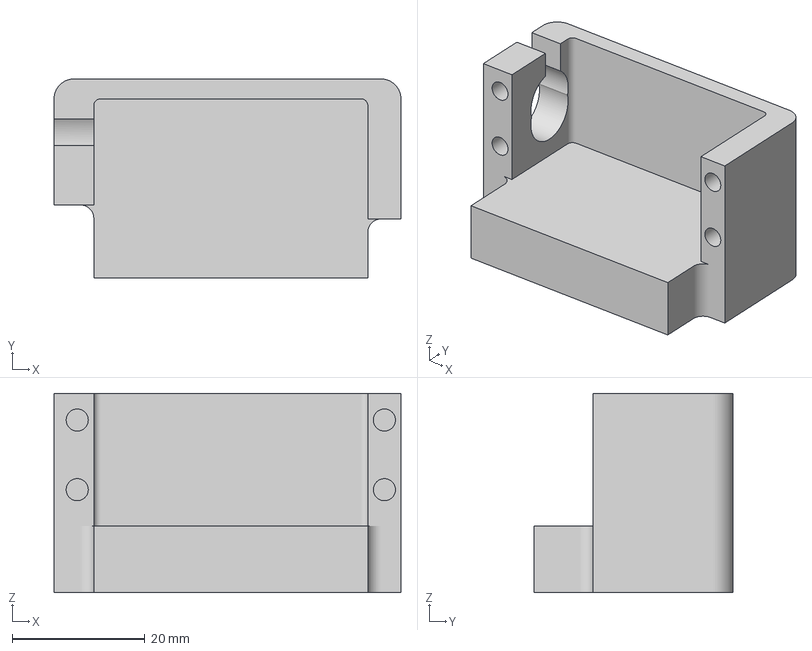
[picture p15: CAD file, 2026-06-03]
models/anteriores/Soporte Servo.3mf
52.3 x 30.0 x 30.0 mm

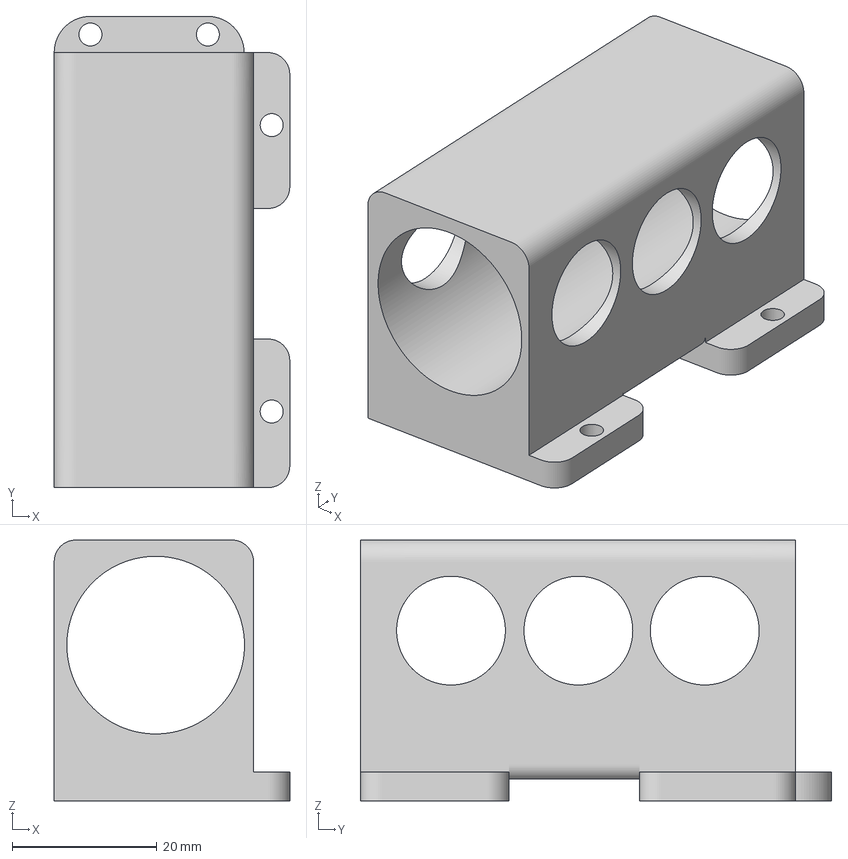
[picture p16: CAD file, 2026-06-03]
models/Soporte Motor VF.3mf
32.5 x 65.0 x 36.0 mm

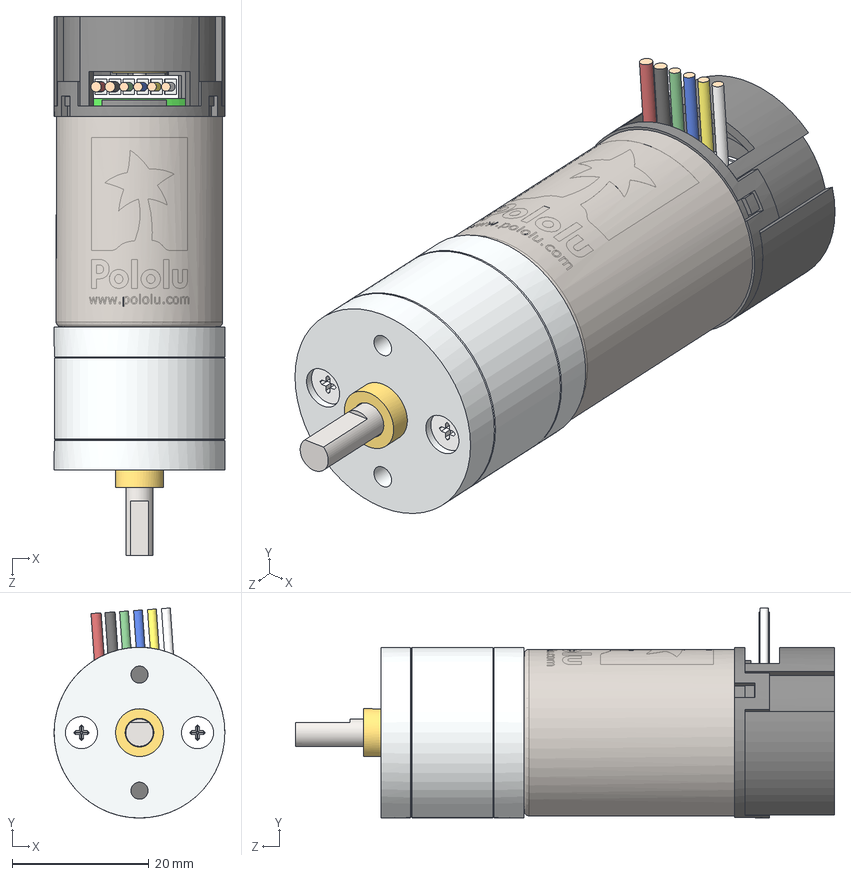
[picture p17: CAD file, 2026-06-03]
models/25d-metal-gearmotor-34-47-encoder.step
25.0 x 30.8 x 79.0 mm

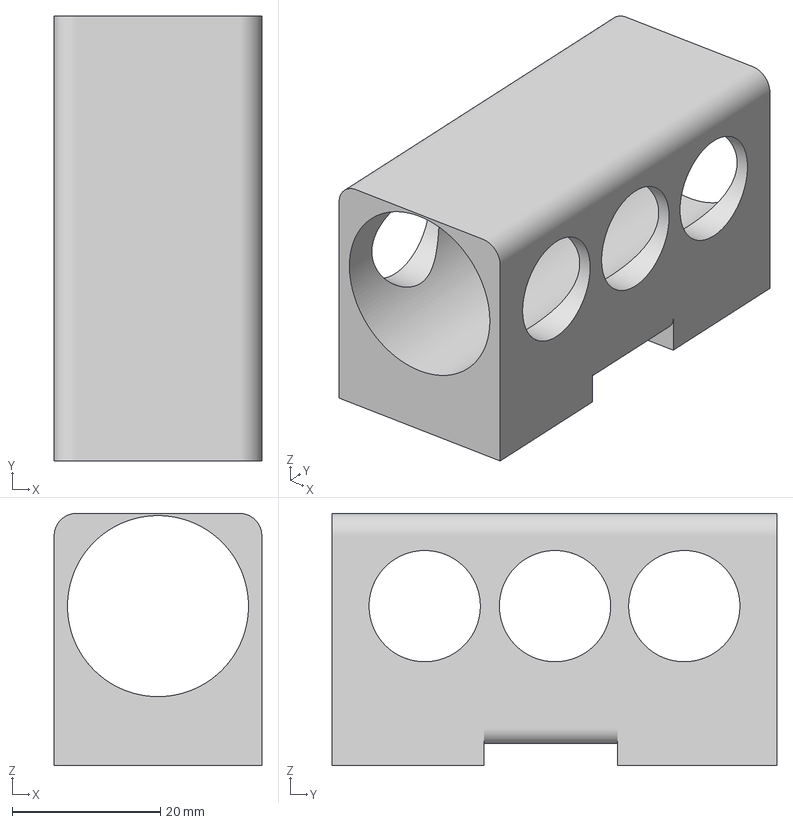
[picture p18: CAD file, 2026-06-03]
models/anteriores/Soporte Motor.3mf
28.0 x 60.0 x 34.0 mm

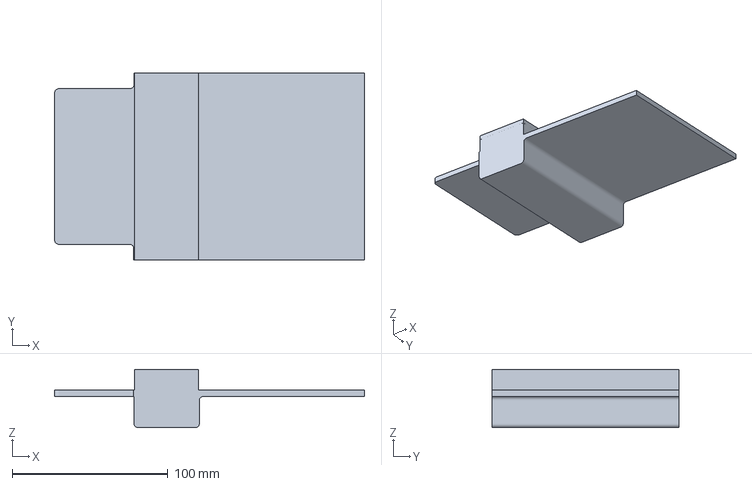
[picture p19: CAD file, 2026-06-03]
models/anteriores/Chassis Arriba V1.3mf
199.0 x 120.0 x 37.4 mm

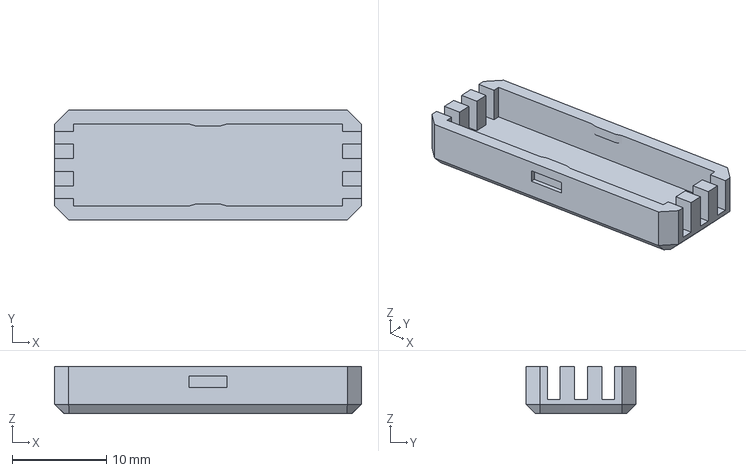
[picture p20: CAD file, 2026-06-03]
models/Canal 3 Cables.3mf
32.6 x 11.7 x 5.04 mm

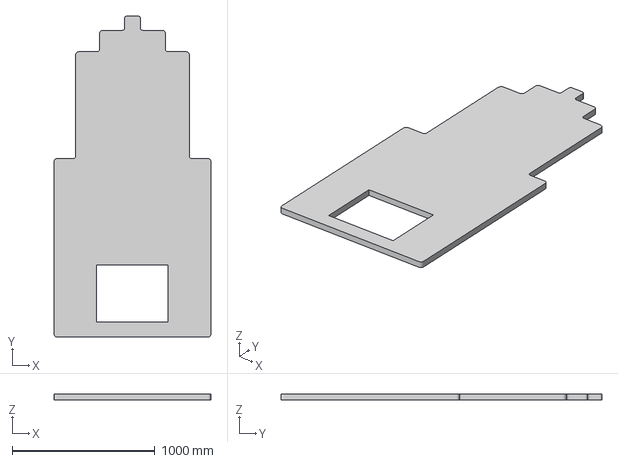
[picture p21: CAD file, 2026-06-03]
models/anteriores/Chassis Abajo V0.3mf
1100.0 x 2250.0 x 40.0 mm

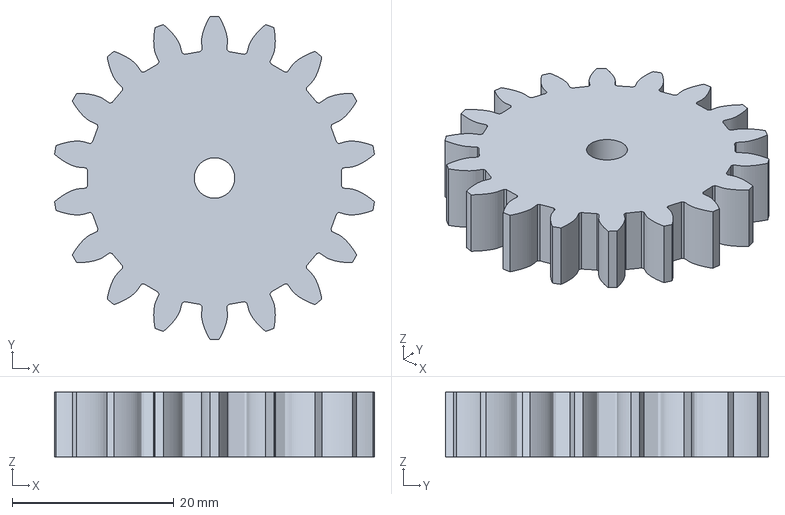
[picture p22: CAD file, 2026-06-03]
models/Gear Diferencial.3mf
39.6 x 40.0 x 8.00 mm

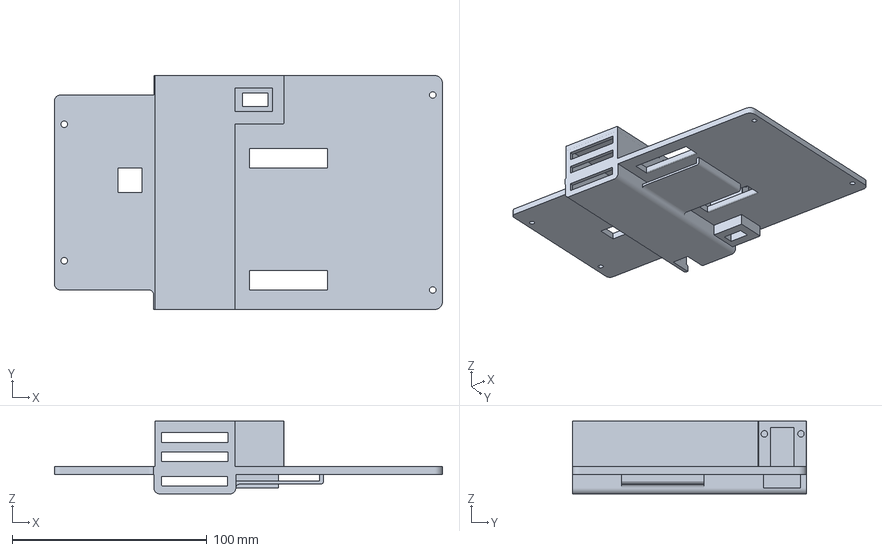
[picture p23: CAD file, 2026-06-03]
models/Chassis Arriba V2.3mf
199.0 x 120.0 x 37.4 mm

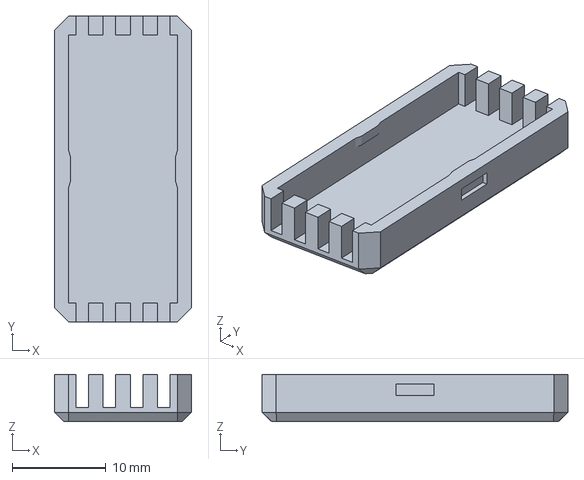
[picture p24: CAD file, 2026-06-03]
models/Canal 4 Cables Tapa.3mf
14.6 x 32.6 x 5.04 mm

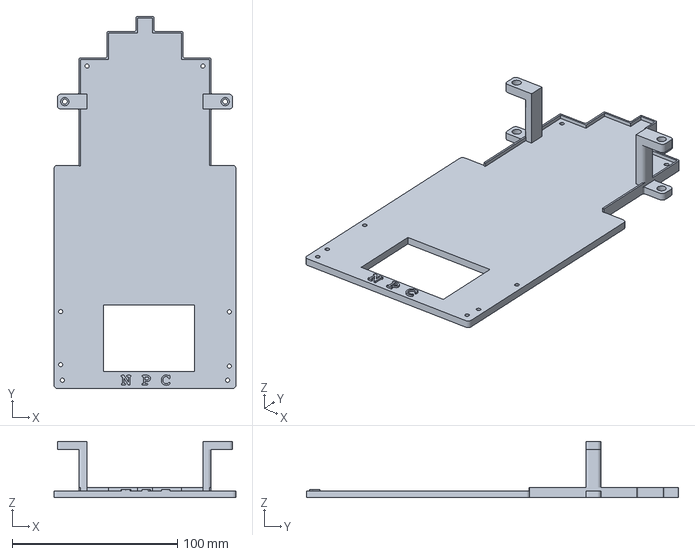
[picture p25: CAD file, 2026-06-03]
models/Chassis Abajo V2.3mf
110.0 x 225.0 x 34.0 mm

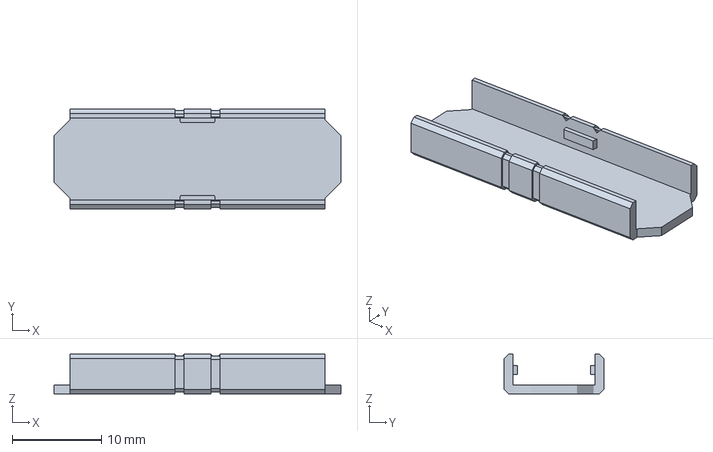
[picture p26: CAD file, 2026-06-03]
models/Canal 2 Cables Tapa.3mf
32.1 x 11.2 x 4.43 mm

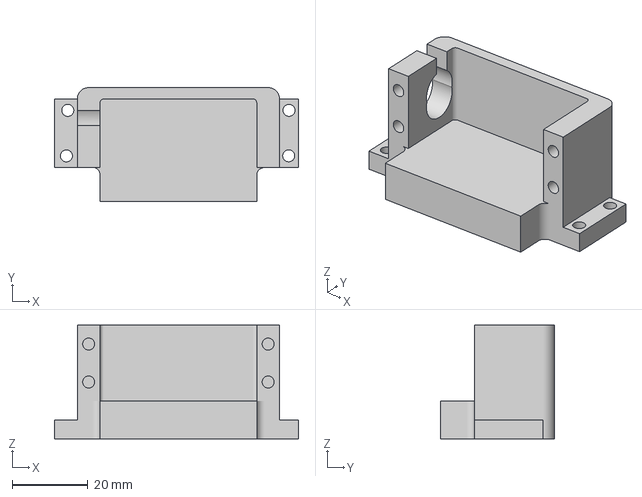
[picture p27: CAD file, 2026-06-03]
models/Soporte Servo VF.3mf
64.3 x 30.0 x 30.0 mm

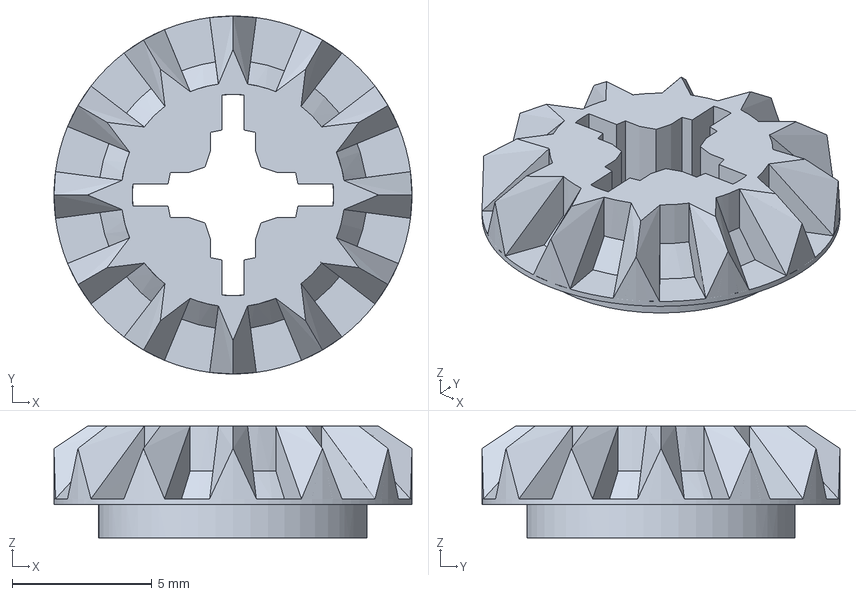
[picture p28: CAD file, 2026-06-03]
models/Gear Box Diferencial.3mf
12.8 x 12.8 x 4.00 mm

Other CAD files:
models/Gear Motor con Flange.3mf
models/Canal 3 Cables Tapa.3mf
models/Canal 4 Cables.3mf
models/Espaciador de Eje.stl
models/Canal 2 Cables Tapa.stl
models/Canal 2 Cables.3mf
models/Canal 2 Cables.stl
models/Canal 3 Cables Tapa.stl
models/Canal 3 Cables.stl
models/Canal 4 Cables Tapa.stl
models/Canal 4 Cables.stl
models/Chassis Abajo V2.stl
models/Chassis Arriba V2.stl
models/Espaciador Eje.3mf
models/Gear Box Diferencial.stl
models/Gear Diferencial.stl
models/Gear Motor con Flange.stl
models/Repisa.3mf
models/Repisa.stl
models/Soporte Motor VF.stl
models/Soporte Servo VF.stl
models/Sujetador Cables.3mf
models/Sujetador Cables.stl
models/anteriores/Chassis Abajo V0.stl
models/anteriores/Chassis Arriba V1.stl

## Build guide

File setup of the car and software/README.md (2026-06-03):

**En esta carpeta encontraras fotos y archivos que contienen
diferentes procesos que nosotros hicimos para construir el robot como lo conocemos.
Un ejemplo es que cada foto muestra cuando nosotros estabamos haciendo algo para después
integrarlo al carro. Otro ejemplo es el archivo word del setup del py que es un paso a paso del setup**

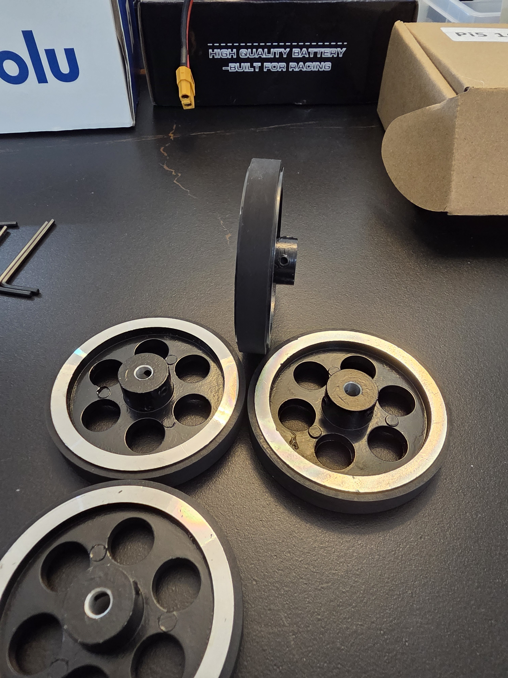
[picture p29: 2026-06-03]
setup of the car and software/Ruedas.jpg

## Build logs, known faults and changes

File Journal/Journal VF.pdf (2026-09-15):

## WRO FUTUROS INGENIEROS 2026

## Journal

## NPC

## “Proyecto Mahoraga”

COLEGIO JEFFERSON
ESTADO MIRANDA
VENEZUELA

MIEMBROS
LEONARDO CARRASQUERO -16 AÑOS JUAN IGNACIO GONZALEZ - 16 AÑOS VU TUE ANH - 16 AÑOS

COACH
ALFREDO GONZALEZ

PORTADA

TABLA DE CONTENIDOS

### 1. INTRODUCCIÓN

### 1.1 Nuestro Equipo

### 1.2 Nuestro Espacio de Trabajo

### 1.3 Experiencia Previa (WRO 2025)

### 1.4 Objetivos para WRO 2026 2. CRONOLOGÍA DEL PROYECTO

### 2.1 Fase 1: Investigación y Planificación

### 2.2 Fase 2: Diseño Conceptual

### 2.3 Fase 3: Prototipado

### 2.4 Fase 4: Pruebas e Iteración

### 1. INTRODUCCIÓN

Este documento presenta el proceso de ingeniería del equipo NPC (Non Player Character), para la competencia WRO Futuros Ingenieros 2026.

La idea es mostrar un Journal o Diario de nuestro proceso de avance en el desarrollo de nuestro robot Proyecto Mahoraga que sirva a otros para poder seguir nuestros pasos.

### 1.1 Nuestro Equipo

Este es nuestro segundo año en competencias de la WRO, con el objetivo de lograr un vehículo verdaderamente autónomo que supere con éxito los retos de la competencia WRO Futuros Ingenieros 2026 a Nivel Nacional y nos permita obtener nuestro cupo en la Final Internacional de Puerto Rico.

Vu Tue Anh, compitió el año pasado en la categoría de Misiones Roboticas, mientras que Leonardo y Juan participaron en la categoría de Futuros Ingenieros, llegando a la Final Nacional de Venezuela donde obtuvimos el 5to Lugar, mientras que en un invitacional en Weifang, China logramos el 1er Lugar.

### 1.2 Nuestro Espacio de Trabajo

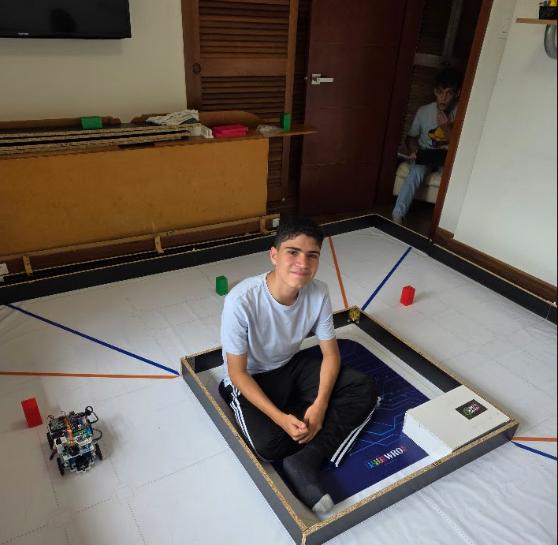
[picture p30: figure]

Trabajamos en el Colegio Jefferson todos los viernes y organizamos reuniones en casa de Leonardo semanalmente. Además, avanzábamos de manera independiente durante la semana.

Contamos con una pista con las condiciones y medidas originales de la WRO para hacer pruebas y ajustes.

Además, tenemos diversas herramientas e inventario de piezas y partes: Impresora 3D BambuLab P2S, equipo de soldadura, multímetro, destornilladores y herramientas en general. Piezas eléctricas y mecánicas compradas de repuesto, así como multiplicidad de cables, termoencogibles.

### 1.3 Experiencia Previa (WRO 2025)

Este es nuestro segundo año en competencias de la WRO, el año pasado participamos con “Crazy Diamond”, obteniendo una calificación destacada en los 3 eventos regionales que participamos y logrando la 2da puntación más alta de toda la ronda clasificatoria a la Final Nacional de Venezuela, donde obtuvimos el 5to Lugar.

### 1.4 Objetivos para WRO 2026

La competencia 2025 fue nuestra primera experiencia, aprendimos muchísimo y el reto era mejorar para el 2026 y alcanzar la Final Internacional.

Aprendimos que:

Nuestra primera experiencia en la competencia de 2025 fue un gran aprendizaje. Aunque el panorama fue retador, nos sirvió para darnos cuenta de lo que realmente necesitábamos para subir de nivel y ponernos como meta clara alcanzar la Final Internacional este 2026.

Estas fueron las lecciones clave que nos dejaron esa primera participación:

1. El tiempo es clave: Entendimos que no podíamos perder ni un día. En la temporada pasada empezamos a trabajar en abril, pero para este ciclo nos propusimos arrancar en enero, apenas la WRO oficializó el reto y sus nuevas reglas. Esos tres meses de ventaja hicieron toda la diferencia para planificar con calma.
2. Evolución en hardware y software: Ver de cerca las soluciones que llevaron los equipos a la Final Internacional 2025 nos abrió los ojos. Nos dimos cuenta de que, si queríamos ser competitivos, nuestro robot actual no iba a bastar; necesitábamos un salto de calidad drástico tanto en los componentes físicos como en la arquitectura del código.
3. Aprender de la comunidad: Pasamos mucho tiempo investigando, analizando videos de competencias previas y, sobre todo, estudiando a fondo repositorios de GitHub de equipos exitosos en 2024 y 2025. Gracias a eso, pudimos estructurar una hoja de ruta súper clara con los cambios técnicos exactos que Proyecto Mahoraga necesitaba para este 2026.

Basándonos en nuestra experiencia de 2025, establecimos objetivos para 2026:

Objetivos Técnicos

1) Tener un robot más pequeño y ágil para tener mayor margen en la evasión de obstáculos.
2) Tener un chasis hecho a la medida de las necesidades y no uno comercial como empleamos en 2025.
3) Incorporar un LiDAR para un mapeo robusto de obstáculos y bordes
4) Incorporar un IMU para tener un desarrollo mas robusto que nos permitiera medir de una mejor manera los ángulos de giro y las desviaciones
5) Un microprocesador mas potente para poder tener una fluidez en la transmisión de datos de los sensores y motores.
6) Incorporar un procesador de alta gama como el Raspberry Pi 5 de 16 Gb para garantizar el manejo de las imágenes de la cámara y el LiDAR, al tiempo de centralizar el control del robot.

Herramientas de Gestión
- Comunicación diaria: Mantuvimos un canal activo y constante a través de un grupo de WhatsApp entre nosotros y nuestro coach. Esto nos permitió resolver dudas rápidas, coordinar las sesiones de trabajo y reportar cualquier imprevisto técnico al momento.
- Documentación en la nube: Centralizamos toda nuestra información en Google Drive. Ahí organizamos desde las carpetas de investigación inicial, los avances del código, el registro fotográfico de las pruebas y los resúmenes de cada sesión para no perder el hilo de lo que hacíamos. Todo esto nos sirvió como base para estructurar de manera sólida nuestro Journal.

### 2 CRONOLOGÍA DEL PROYECTO

Metodología de Trabajo

Ciclo de Desarrollo

Adoptamos un enfoque por etapas, pero con tareas que podían coincidir en el tiempo o ser iterativas.

FASES:

### 2.1 Fase 1: Investigación, Planificación y Compra de Componentes 2.2 Fase 2: Diseño Conceptual 2.3 Fase 3: Construcción de Robot “Proyecto Mahoraga” 2.4 Fase 4: Programación, Pruebas e Iteración

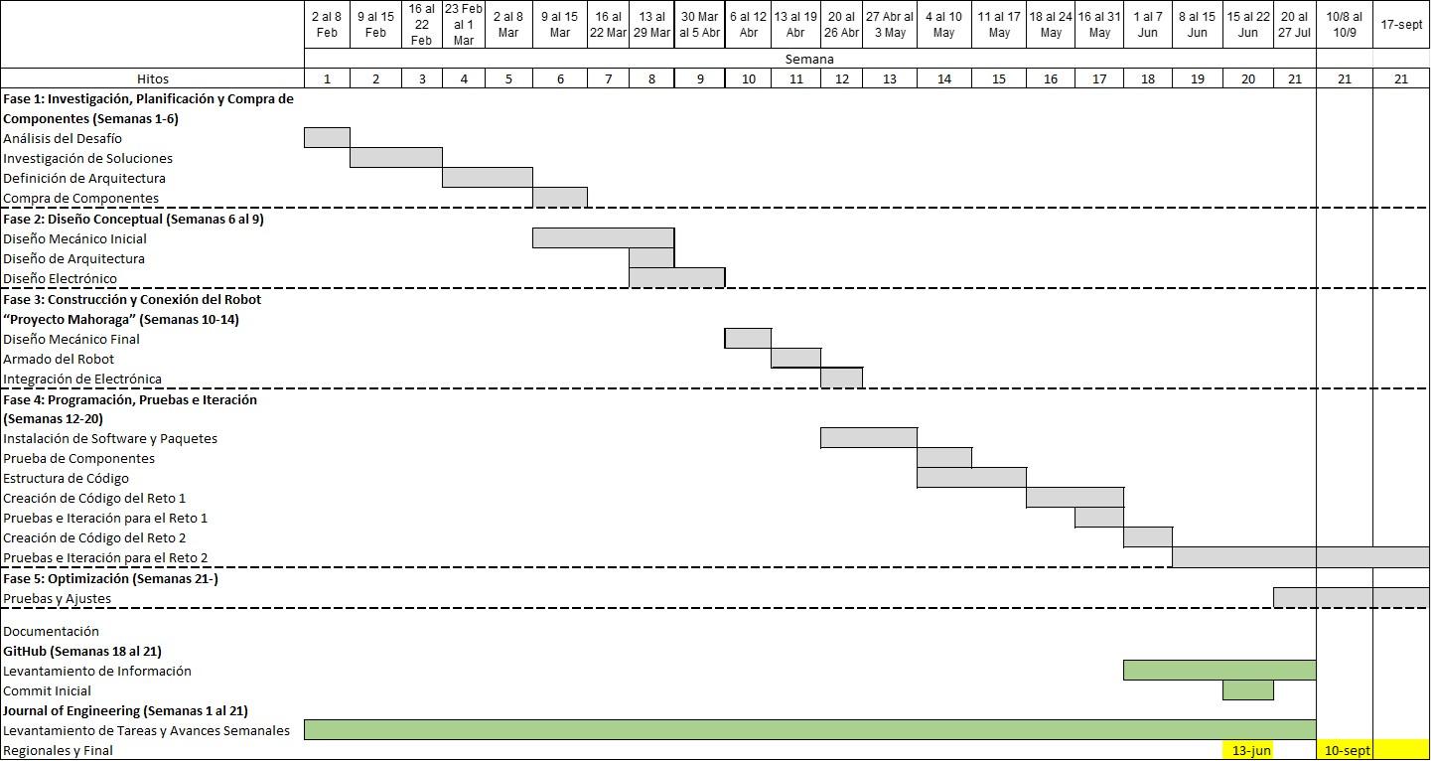
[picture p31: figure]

### 2.1 Fase 1: Investigación, Planificación y Compra de Componentes (Semanas

1-6)

Semana 1: Análisis del Desafío

Comenzamos con una sesión de trabajo leyendo detalladamente las reglas de WRO 2026. Identificamos los cambios respecto a 2025 y como esto podía afectar.

Cambio 1: Reto 2 partiendo del Estacionamiento: Se aclara en las reglas 2026 que los puntos de partida desde el estacionamiento en el reto 2 solo se adjudicarán si el equipo cumple una vuelta efectiva.

Efecto: En 2025, usamos la estrategia de salir desde el estacionamiento y obtuvimos la puntuación pese a no completar 1 vuelta, lo cual sería algo a considerar si decidimos partir del estacionamiento en 2026.

Cambio 2: Se promueve el uso de regla sorpresa, que pese no estar en las normas 2025, no se implementó al menos en Venezuela.

Efecto: Importancia de tener un código lo más simple posible y con anotaciones para identificar ajustes necesarios según el cambio de condiciones.

Cambio 3: Normas y elementos del Github mucho más específicos y explicativos.

Efecto: En 2025 nuestra puntuación del Github tenía importantes posibilidades de mejora y acordamos que eso podría hacer una diferencia sustancial en el 2026.

Adicionalmente, repasamos estrategias a un alto nivel de cómo superar este año los retos, con mayor énfasis en el reto 2 que fue el que más dificultad nos dio en 2025.

2 al 8
Feb

9 al 15
Feb

16 al
22
Feb

23 Feb
al 1
Mar

2 al 8
Mar

9 al 15
Mar

16 al
22 Mar
Hitos | 1 | 2 | 3 | 4 | 5 | 6 | 7
Fase 1: Investigación, Planificación y Compra de Componentes (Semanas 1-6) Análisis del Desafío Investigación de Soluciones Definición de Arquitectura Compra de Componentes

Semana

Semana 2 y 3: Investigación de Soluciones

Si bien esto lo abordamos en la documentación de “Selección de Componentes y Comparación con 2025” creemos que al ser parte importante de nuestras decisiones lo repetimos acá.

Investigamos soluciones de los equipos con los mejores puntajes en la Final Internacional 2025. Hicimos cuadros comparativos de los componentes que utilizaron, así como el tipo de lenguaje de programación.

Analizamos y sacamos conclusiones de la información en los repositorios y los videos en Youtube.

Lo que aprendimos de otros equipos:

- Solo 3 del Top 15 uso soluciones en Lego EV3, pero además lo descartamos porque queríamos trabajar con soluciones más avanzadas.
- El Raspberry Pi y principalmente la versión 5, era el controlador más utilizado entre los equipos de mayor puntaje.
- El Arduino era usado por solo 2 equipos y solo como microcontrolador acompañante. Evidenciando la desventaja con la que trabajamos en 2025. ESP32 y el Raspberry Pico 2 resultaron como los microcontroladores más usados.
- 6 del top 10, utilizaron un LiDAR y tenían estrategias robustas de detección.
- Prácticamente todos los equipos utilizaron un IMU, versiones BNO085 y BNO055.
- Los equipos utilizaron controladores de motores más modernos y avanzados que el L298N que utilizamos en 2025, recomendado solo para experimentos de robótica simple.
- La mayoría de los equipos usaron chasis y piezas hechas en 3D. Aquellos que usaron chasis comerciales hicieron modificaciones importantes y complementaron con piezas impresas en 3D.
| Equipo | | | | | Documentación | ∑ | Github
1. | 6030 - Double-X | 30.0 (30) | 30.0 (37) | 62.0 (63) | 62.0 (49) | 29.3 | 121.3 (79) | https://github.com/ejm22/WRO-FE-XX
2. | 6018 - KMIDS GFM | 30.0 (43) | 30.0 (43) | 62.0 (60) | 62.0 (63) | 29.0 | 121 (103) | https://github.com/Chayanon-Ninyawee/KMIDS-GFM-Future-Engineer-2025
3. | 6001 - STORMS NGR | 30.0 (24) | 30.0 (22) | 62.0 (87) | 62.0 (69) | 29.0 | 121 (91) | https://github.com/MoCsabi/WRO2025-FE-StormsNGR
4. | 6009 - FireOnAllCylinders | 30.0 (41) | 30.0 (44) | 47.0 (65) | 62.0 (73) | 27.3 | 119.3 (114) | https://github.com/kirkhu/WRO2025_FE-Fire-On-All-Cylinders
5. | 6003 - ANTİ | 30.0 (22) | 0.0 (180) | 62.0 (47) | 47.0 (42) | 27.0 | 119 (69) | https://github.com/atakanersoy/WRO2025_FE_ANTi
6. | 6045 - Team LazyGo | 30.0 (45) | 5.0 (14) | 29.0 (53) | 62.0 (110) | 27.0 | 119 (155) | https://github.com/A-N-M-Noor/LazyGo_WRO2025
7. | 6006 - KMW Battlepillars | 30.0 (63) | 30.0 (64) | 62.0 (162) 27.0 (110) | 27.0 | 119 (225) | https://github.com/Battlepillars/Wro
8. | 6042 - SQ-391 | 30.0 (77) | 30.0 (99) | 62.0 (135) 62.0 (99) | 26.0 | 118 (176) | https://github.com/Alhadi1123/SQ-391_WRO_Future_Engineers_2025
9. | 6029 - Ishikawa KOSEN | 30.0 (112) 30.0 (124) | 62.0 (157) 11.0 (38) | 25.7 | 117.7 (269) | https://github.com/UNOsan118/WRO2025_FE_INCT
10. | 6011 - QYZYLORDA Flame | 30.0 (63) | 30.0 (51) | 47.0 (114) 62.0 (120) | 25.0 | 117 (171) | https://github.com/QZOFlameFE/FE2025_1st_repo_ByFlame
11. | 6024 - Greenbotics | 30.0 (45) | 30.0 (52) | 62.0 (75) | 62.0 (61) | 24.0 | 116 (106) | https://github.com/Devansh-awat/greenbotics
12. | 6012 - shahrood RC | 30.0 (41) | 0.0 (180) | 44.0 (120) 62.0 (141) | 24.0 | 116 (182) | https://github.com/ShahroodRC/WRO2025-FE-ShahroodRC
13. | 6058 - X-UniTech | 30.0 (34) | 30.0 (31) | 47.0 (76) | 62.0 (89) | 23.3 | 115.3 (120) | https://github.com/vunxiuxuan/X-UniTech-IPGKS
14. | 6025 - Paraducks | 30.0 (66) | 30.0 (76) | 62.0 (173) 18.0 (46) | 21.7 | 113.7 (239) | https://github.com/DevShah1407/WRO-Paraducks
15. | 6052 - AZE 44 | 30.0 (61) | 30.0 (64) | 8.0 (27) | 62.0 (177) | 20.3 | 112.3 (238) | https://github.com/coolboy19521/AZE44

Partidos
clasificatorios | Partidos finales

Acá anexamos un cuadro comparativo.

Equipo | Cámara | Sensor de Distancia | Controlador de Motores | Lenguaje de Programación | Controlador Principal | Controlador Secundario | IMU | Motor | Servo | Diferencial | Convertidor de Voltaje | Otro | Largo | Acho
LazyGo | Logitech C270 | LiDAR (RPLidar C1) | VNH2SP30 Motor Driver | Python, C++ (ROS2), | Raspberry Pi 5 | ESP32 Microcontroller. ESP-WROOM-32 30/38Pin | BNO055 9‑Axis IMU | 25GA Gear Motors + Encoder | PS1171MG Servo | LEGO Differential (Gen 3) | 5V 20A Buck Converter | | 20 | 10
SQ-391 | Raspberry Pi Camera Module 3 | 4 Ultrasónic o (URM09) | DRV8871 Motor Driver | Python (ROS Noetic), | Raspberry Pi 4 Model B | ESP32-WROOM-32E | BN0085 | Core DC Motor (6 V, 400 RPM) | TowerPro MG996R Servo y Micro Servo Motor SG90 | | XL4005 DC-DC Step-down | PCA9685 Servo Driver HAT
Battlepillars | Raspberry Pi Camera Module 3 Wide | LiDAR (RpLidar S2) | Quicrun WP 1080–G2 | Python | Raspberry Pi 5 | Servo Controller (Adafruit) | SparkFun Optical Tracking Odometry Sensor. Porque el motor no tiene encoder | 23-turn brushed 370-size LaTrax® motor with bullet connectors | Traxxas Waterproof Sub-Micro Servo (model number 2065A | | Pololu 5V Step-down | | 19 | 12,8
KMIDS-GFM | Fish-Eye Lens RPi 5MP IR Camera | LiDAR (RPLidar S2) | DRV8871 Motor Driver | C++ | Raspberry Pi 5 | Raspberry Pi Pico 2 | BNO085 | N20 Motor, 6V 500 RPM | Servo: S0009M | LEGO differential gear system | UPS EP-0136 <br> DC-DC Boost Step-Up | Transistor: N-Channel MOSFET | 24,4 | 12
Ishikawa KOSEN | 2DOF Monocular Camera | LiDAR (STL-19P D500) | RRC Lite Controller | Python (ROS 2) | Raspberry Pi 5 | RRC Lite Controller | BNO055 9‑Axis IMU | DC Geared Motor w/ Encoder | Hiwonder LFD-01 Servo | | Hiwonder RRC Lite Controller | Control Board for LiDAR incluido en el kit del Lidar con el RRC Controler | 19,5 | 15
Double-X | Pi Camera 3 Wide | Basado en Visión (Cámara) | DRV8825 (Stepper driver) | Python y C++ | Raspberry Pi 5 | Arduino Uno R3 | No USA | NEMA 17 Stepper Motor | HS 225BB Servo Motor | | No especificado | | 28,5 | 13,5
Greenbotics | Raspberry Pi Camera Module 3 | ToF (VL53L1X/L 8CX) y Ultrasónic o (URM09) y VL53L8CX | TB6612FNG Dual Motor Driver | Python | Raspberry Pi 5 | | BNO055 IMU | LEGO EV3 Medium Motor, | Servo SG90 | LEGO differential gear system | XY-3606 | Multiplexor I2C (TCA9548A)
StormsNGR | Cámara (Modelo no especificad o) | LiDAR sensor STL-19P, D500 developme nt kit | DRV8871-MK | Python y C | Raspberry Pi 5 4GB | Microcontroller (ESP) NodeMCU-32S | BNO085 | Hiwonder JGB37-520R30-12 | Steering servo Carson CS-3 | Carbon fiber Lego technic axl | XL4015-3D-STDN-PSU | | 27 | 19,7
AZE44 | Raspberry Pi Camera | Yahboom T-mini Plus LiDAR + 1 HC-SR04 | TB6612FNG Dual Motor Driver | Python (ROS 2), | Raspberry Pi 5 | Raspberry Pi Pico W RP2040 | BNO085 | DC Motor con Encoder | Servo Motor TD8120MG | | | | 19,5 | 15
Fire-On-All-Cylinders | SONY IMX477 camera module | 2 HCSR04 Ultrasónic o e Infrarrojo | L293d motor controller | | Nvidia Jetson Orin Nano | Raspberry Pi Pico W RP2040 | BNO055 IMU | | | Lego 62821b Differential Gear | | | 15,1 | 9,27
ANTi | GC2145 2MP Camera | ToF (VL53L1X y VL53L3CX) | DRV8833 | Python (MicroPython), C++ | STM32H747 (Visión) | nRF52832 (Sensores) | LSM6DSOX | Motor DC N20 de 1500 RPM con codificador | servomotor submicro Feetech FS0307 | | SX1308 Voltage Booster LiPo Rider Plus | | 11 | 5,7

Semana 4 y 5: Definición de Arquitectura

Definimos la arquitectura general de nuestro vehículo y comparamos entre distintos tipos de alternativas para cada componente. Se dio mucho peso en aquellos componentes más robustos, pero también en aquellos que ofrecieran mayor compatibilidad con el resto de los componentes.
Las decisiones de arquitectura tomadas se explican con más detalle en “Selección de Componentes y Comparación con 2025”, pero resumimos a continuación la lista de componentes.

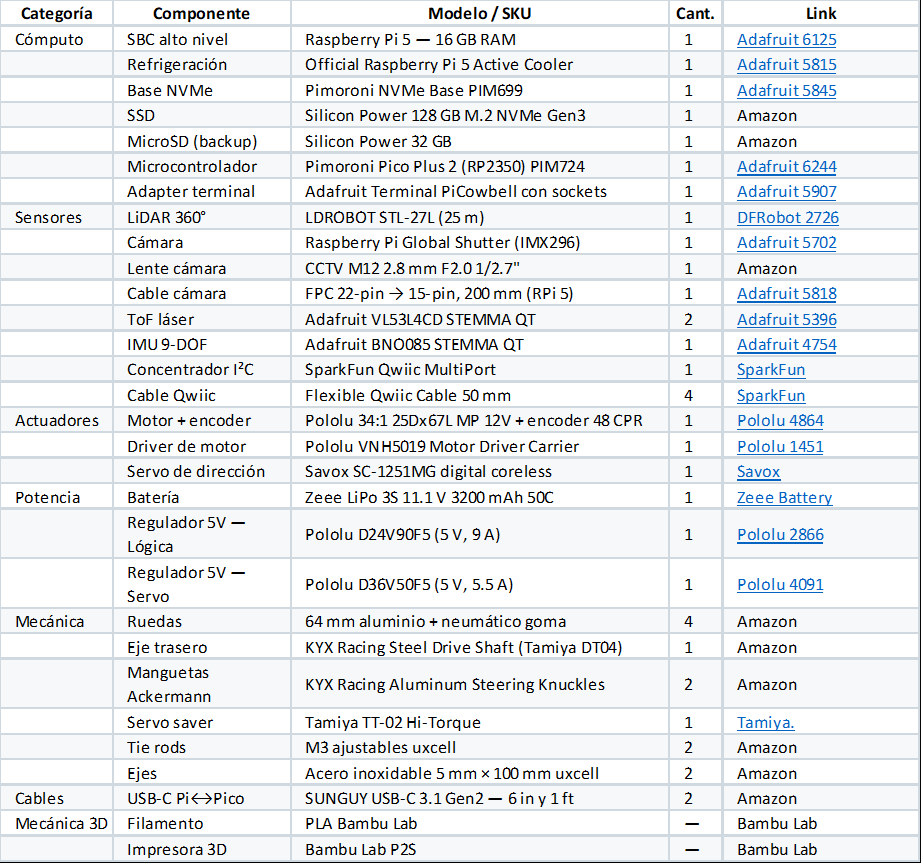
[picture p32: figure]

Semana 6: Compra de Componentes

Una vez que identificamos lo que necesitábamos, y a diferencia de 2025, cuando usamos componentes más básicos, decidimos importar la mayoría de las piezas para conseguir mejores precios y más variedad. Para evitar problemas con los tiempos de envío si algo fallaba, dejamos de lado las partes genéricas y priorizamos marcas reconocidas. Toda la compra la gestionamos a través de Amazon.com y directamente en las páginas oficiales de fabricantes especializados, como Pololu para los motores y componentes electrónicos, y Adafruit para los sensores y microcontroladores

### 2.2 Fase 2: Diseño Conceptual (Semanas 6-9)

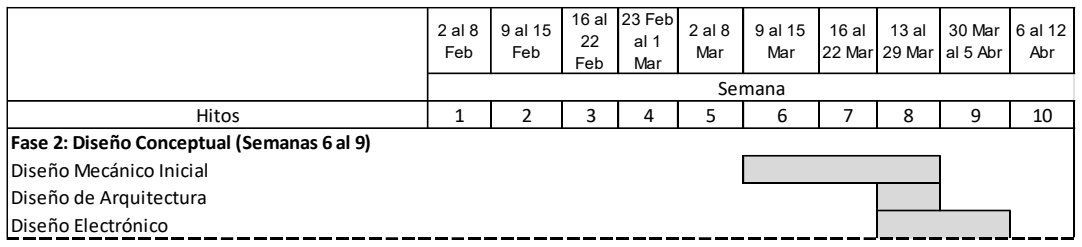
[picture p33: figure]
2 al 8 Feb; 9 al 15 Feb; 16 al 22 Feb; 23 Feb al 1 Mar; 2 al 8 Mar; 9 al 15 Mar; 16 al 22 Mar; 13 al 29 Mar; 30 Mar al 5 Abr; 6 al 12 Abr; Hitos; Diseño Mecánico Inicial Diseño de Arquitectura Diseño Electrónico; Semana

Semana 6 a 8: Diseño Mecánico Inicial

Con la compra de los componentes y en espera de su llegada, empezamos a avanzar en la definición de cómo podríamos distribuir los componentes elegidos en un espacio físico lo más limitado posible para minimizar el tamaño del vehículo, uno de los principales objetivos que nos habíamos puesto.

Utilizamos pedazos de cartón con el tamaño que obtuvimos de las características de cada componente en su página web y definimos un tamaño de chasis y distribución ideal.

Este proceso nos llevó a varias iteraciones, que se fue terminando de definir una vez que llegaron los componentes y que incluso llevó a al rediseño en varias oportunidades del chasis como se comenta en la siguiente Fase 3.

Fase 2: Diseño Conceptual (Semanas 6 al 9)

Semana 8: Diseño de Arquitectura

Definimos la arquitectura principal, que iba a manejar el Raspberry Pi 5 y que iba a manejar el Raspberry Pico 2 para garantizar la mayor eficiencia y la menor complejidad de integración.

Por la experiencia de los otros equipos, que el microcontrolador era para manejar el volumen de data de los sensores más sencillos, pero con alta frecuencia y por eso el Pico Plus 2 era ideal para manejar al Motor, Servo y el IMU BNO085 y TOF. Si bien el Pico 2 Plus es potente sabíamos que la carga más pesada y la lógica del control era tarea para la Raspberry Pi 5 que con 16 Gb tiene la potencia para manejar la lógica, el LiDAR y la Cámara.

Semana 8 a 9: Diseño Electrónico

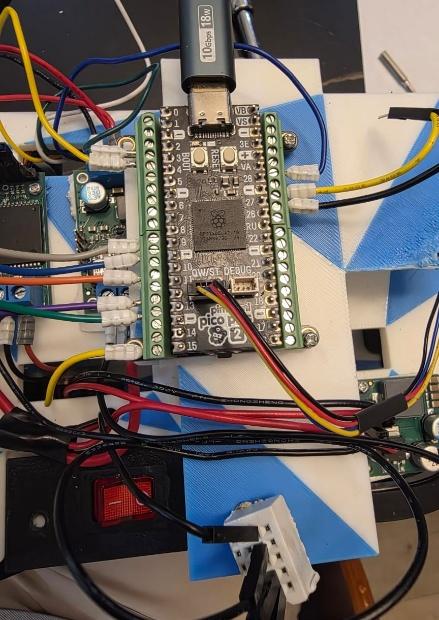
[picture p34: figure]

A la espera de los componentes, fuimos avanzando en el diseño eléctrico y en la definición de las conexiones de cableado tanto de energía como de conexión entre los distintos componentes. Este proceso fue refinado luego de la llegada de los componentes por se identificaron mejores eficiencias, para evitar cables largos o atravesados, lo cual se explicación más detalle en la Fase 3.

Se prefirió utilizar cables Dupont pero garantizando que fueran 20 AWG y no el tradicional 22 AWG, esto para garantizar un mejor flujo de corriente y evitar conexión débil. Adicionalmente dado que el Pico 2 Plus estaba conectado en un Adafruit Terminal PiCowbell con de sockets y los reguladores de voltaje también usaban sockets, para esas conexiones sustituimos los conectores Dupont por puntas virola o de puntas huecas, que garantizan un mejor ajuste dentro del socket.

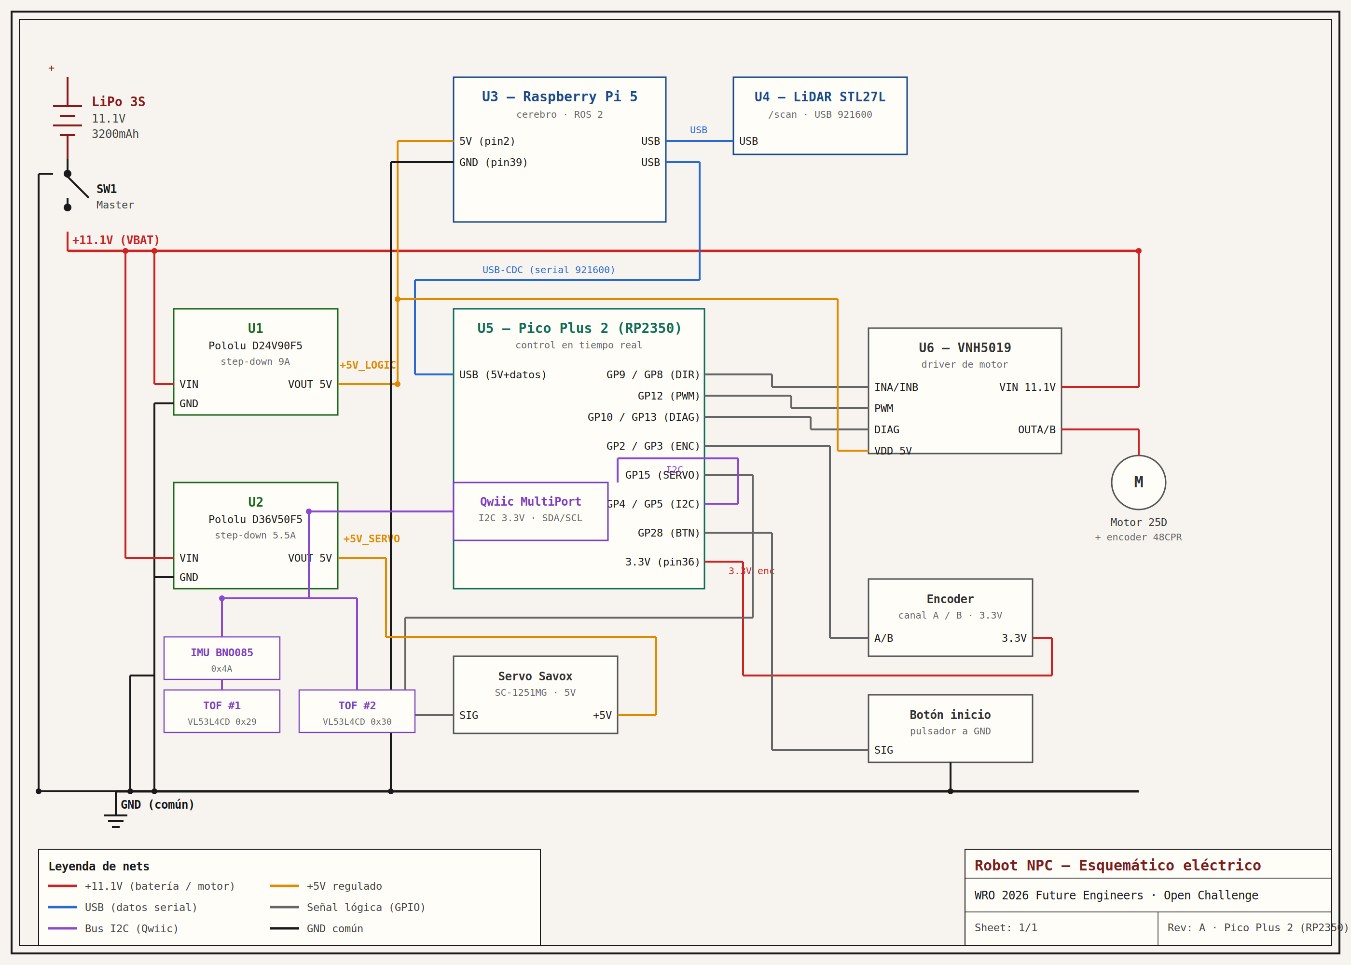
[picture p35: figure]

### 2.3 Fase 3: Construcción y Conexión del Robot “Proyecto Mahoraga”

(Semanas 10-14)

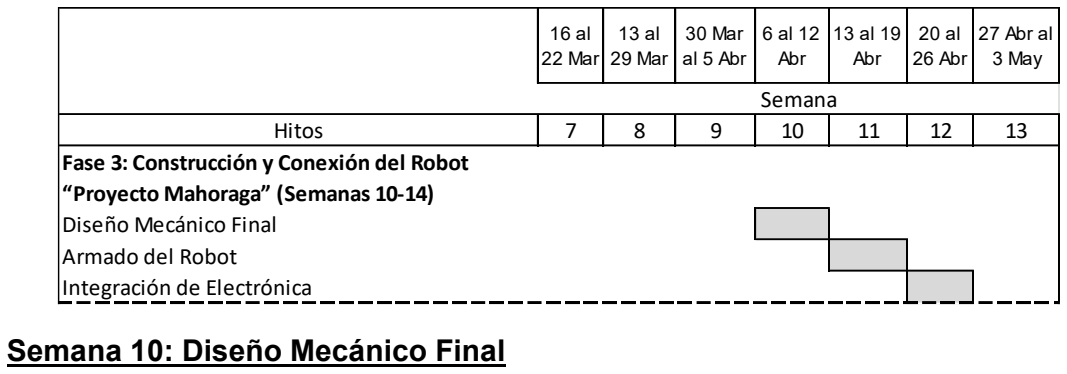
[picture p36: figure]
Semana 10: Diseño Mecánico Final; 16 al 22 Mar; 13 al 29 Mar; 30 Mar al 5 Abr; 6 al 12 Abr; 13 al 19 Abr; 20 al 26 Abr; 27 Abr al 3 May; Hitos; Diseño Mecánico Final Armado del Robot Integración de Electrónica; Semana

Con la llegada de los componentes, comenzamos a armarlos y revisarlos.

Fase 3: Construcción y Conexión del Robot “Proyecto Mahoraga” (Semanas 10-14)

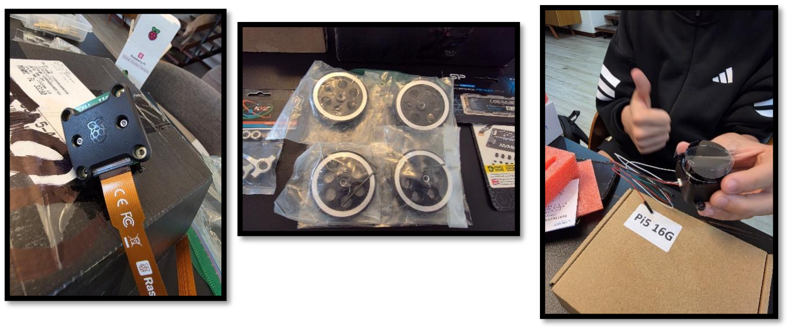
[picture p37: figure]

Durante esa semana nos enfocamos por completo en la estructura física del robot, pasando de prototipos básicos a una solución definitiva mediante impresión 3D:

- Diseñamos e imprimimos una versión base del chasis inferior y superior. El objetivo principal de este primer modelo fue evaluar a escala real la distribución espacial de los componentes y verificar que todo encajara físicamente.
- Definimos y aseguramos un compartimiento especial dedicado exclusivamente a la batería, garantizando que quedara fija y no afectara el centro de gravedad del vehículo y fuera fácil de reemplazar sin afectar otros componentes.
- Tras las primeras pruebas, modificamos el chasis para mejorar el campo de visión del LiDAR. Para lograrlo, reubicamos el servo motor, rediseñamos el habitáculo de la batería para que fuera más seguro y organizamos mejor el enrutamiento de los cables. Todo esto nos permitió aprovechar el espacio y mantener un chasis compacto, logrando la agilidad que queríamos.

Todos los archivos de las piezas que modelamos e imprimimos en 3D quedaron organizados en nuestro GitHub dentro de la carpeta /models

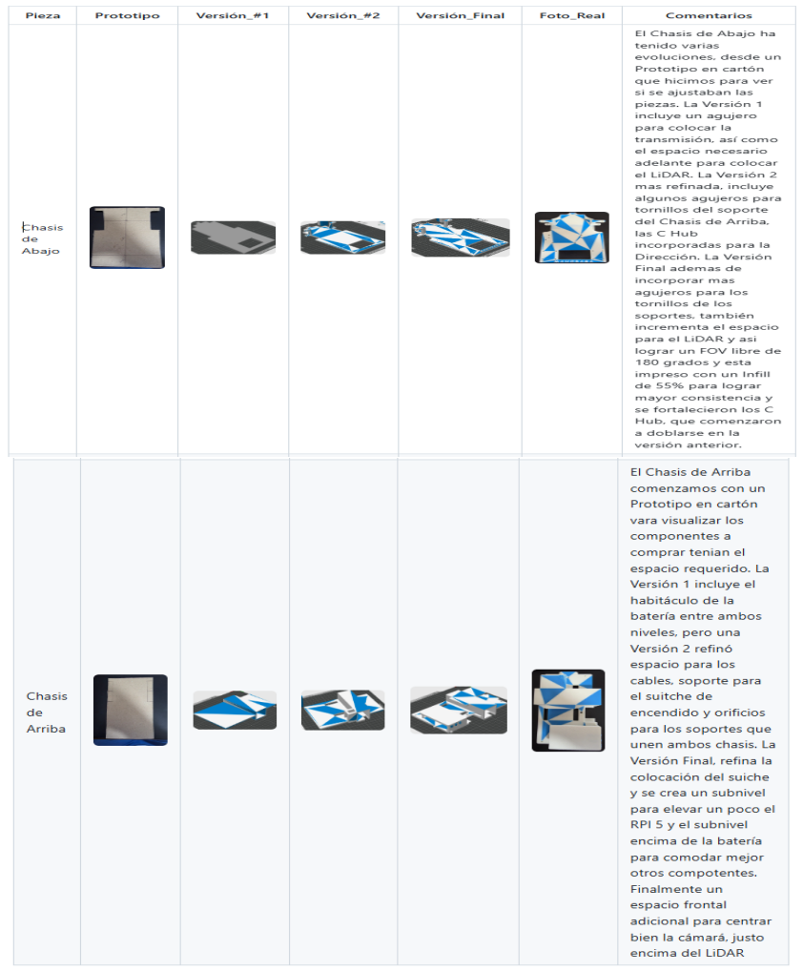
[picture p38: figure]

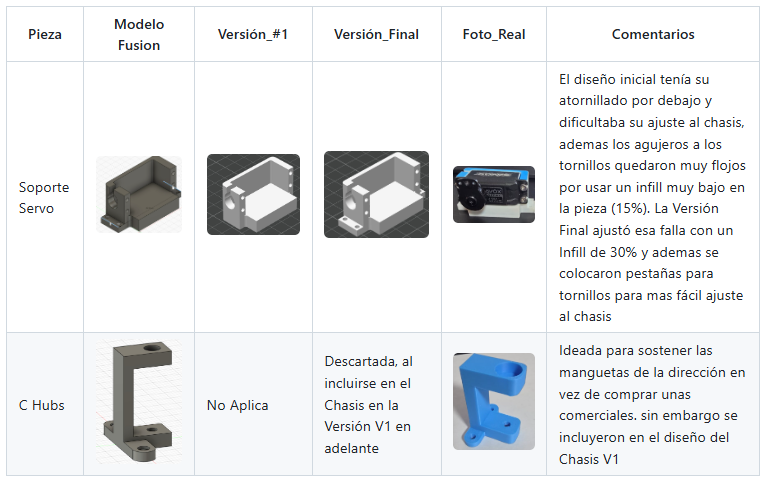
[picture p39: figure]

Semana 11: Armado del Robot

Resumen del orden recomendado:

1. Imprimir todas las piezas
2. Ensamblar diferencial: insertar engranajes cónicos en Gear Box Diferencial

El diferencial va ajustado en el espacio considerado en el chasis para él, colocando los primeros soportes y los espaciadores hechos a la medida para garantizar que la caja del diferencial no se deslice de lado cuando gire el motor

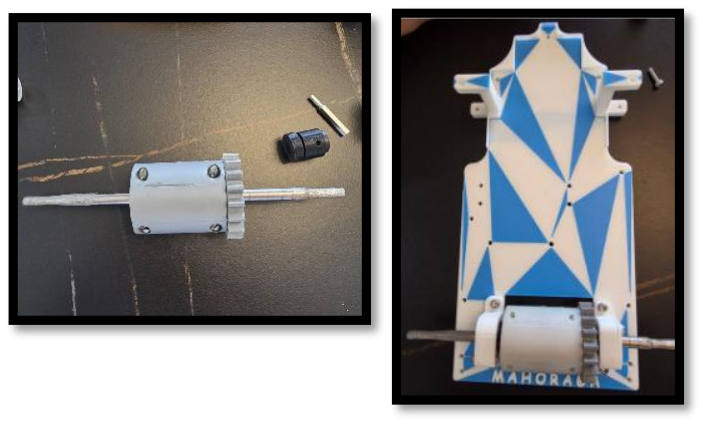
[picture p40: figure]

3. Montar eje trasero KYX con diferencial en el Chasis Abajo ajustando con sus Soportes y Espaciadores. Colocando las Ruedas Traseras de Aluminio de 11 mm de grosor.

El otro par de soportes se incluyen para evitar que no quede recto la transmisión, como pasaba en la versión anterior del Chasis por el peso de la caja del diferencial. Se ajustan las ruedas y se revisa que queden bien sujetas y a la misma distancia del chasis a cada lado.

4. Montar Motor Pololu 34:1 con Soporte Motor y Gear Motor con Flange

Los agujeros del chasis garantizan que el soporte del
motor quede ubicado donde los engranajes del motor y
del diferencial estan alineados.

Importante: El engranaje del Motor impreso en Nylon, permite a diferencia del PLA mayor resistencia a la fricción.

5. Montar servo Savox detrás de las ruedas delanteras en su Soporte Servo VF

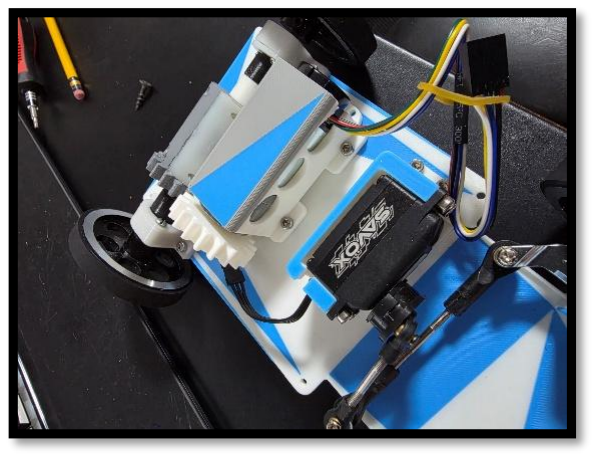
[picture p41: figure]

6. Conectar manguetas KYX + tie rods M3 + servo saver Tamiya

Las barras se atornillan a las manguetas y estas a las C-Hubs del chasis. Las tierods son ajustables para lograr la alineación con el centro del servo. El soporte del servo se fija al chasis y se atornilla el tierod al Servo Saver.

Se debe ajustar para garantizar la alineación con servo centrado

7. Colocación del LiDAR STL27L

El LiDAR se atornilla en la parte frontal asegurando que quede fijo y garantice un Field of View de 180 grados.

8. Colocar Soportes de Chasis de Arriba

Importante: Los agujeros del chasis superior e inferior estan alineados para colocar los soportes de 6cms y así unir ambos chasis, garantizando el espacio con holgura para que los componentes y el subnivel de la batería entren sin problema.

9. Colocación del Chasis de Arriba

10. Montar VNH5019, reguladores con batería LiPO S3 en el primer piso

Continuamos con la parte eléctrica, colocando el VNH5019 y el Regulador Central que reciben energía de la batería a través del suitche de encendido

El detalle del cableado está en la siguiente sección, cable por cable y componente por componente.

11. Colocar y cablear el Regulador del Servo

Arriba en la parte frontal ubicamos el regulador D36V50F5, encargado exclusivamente del servo. Recibe la energía a través del switche y la envía al Servo.

Pasamos los cables por los
agujeros del chasis para conectar
con el servo que está abajo. Para asegurar los cables Dupont utilizamos un sujetador.
12. Montar el Pimoroni Pico Plus 2 y cablearlo

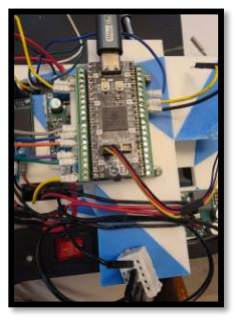
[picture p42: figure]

El Pico Plus 2 va montado encima del Adafruit Terminal PiCowbell for Pico with Pre-Soldered Sockets. Los sockets son de mucha utilidad porque garantizan que los cables no se van a salir porque están atornillados.

Posicionamos la Pico Plus 2, encima del compartimiento de la batería. Queda centrado en el vehículo, lo cual era importante porque es el componente que más conexiones lleva (VNH5019, Encoder, Botón de Arranque, RPI5, IMU y TOF).

13. Colocación de Raspberry Pi 5

La RPI5 la ubicamos en la parte trasera y sus conexiones principales son con el Pico 2 Plus y el LiDAR, como la comunicación es por USB es importante tener cables muy cercanos a la medida necesaria. Para armar el NVME seguimos el paso a paso de la página oficial de Pimoroni.

14. Colocación de IMU + Botón de Inicio

Al lado del Pico 2 Plus, colocamos una protoboard y ahi encajamos el Botón de Inicio y el IMU BNO085, asegurandonos que no utilicen las misma lineas de conexión. Si bien el IMU se conecta por Qwiic los pines pueden interferir.

15. Colocación de Cámara

Colocación de la Cámara en su soporte en el Piso de Arriba con 60 grados de inclinación. Proyecto Mahoraga queda totalmente armado y listo luego de ajustar la programación.

Consideraciones de diseño final:

- Centro de gravedad bajo para estabilidad
- Cámara al frente, elevada para mejor visión
- Batería centrada para balance
- Fácil acceso a electrónica para debugging
- LiDAR abajo y adelante para mejor escaneo de pista

Semana 12: Integración de Electrónica

Conexión de Corriente:

Distribución de corriente entre los dos reguladores de voltaje, decidiéndose dejar el servo con un regulador separado dado que podía generar mayores picos y perturbar la estabilidad de la conexión del Raspberry Pi 5.

Se realizó conexión de la batería Lipo S3 11.1v pasando por el interruptor a:
1) Controlador del motor VNH5019
2) Pololu 5V, 9A Step-Down Voltage Regulator D24V90F5 y
3) 5V, 5.5A Step-Down Voltage Regulator D36V50F5.

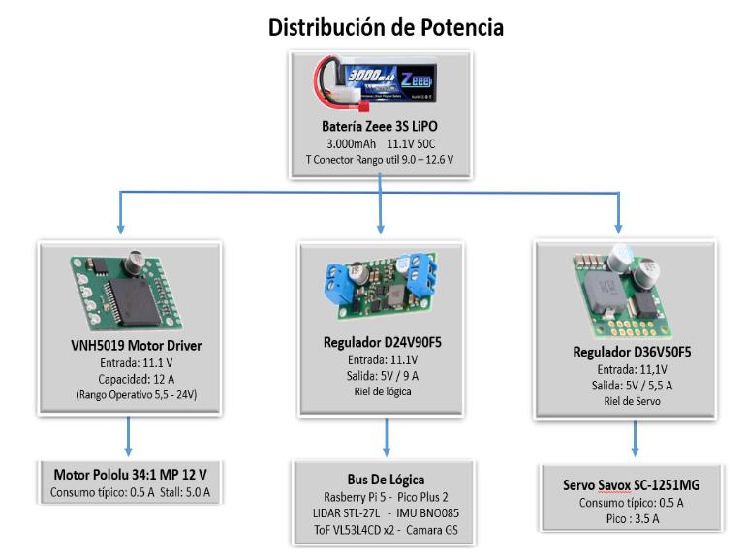
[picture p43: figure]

Conexión de Cableado de Conexiones:

- Decisión de conectar el Raspberry Pi 5 con el Pico 2 Plus, a través de USB en vez de UART, por facilidad de conexión y simplicidad, pese a su mayor volumen logramos ubicarlo eficientemente.
- Se realizó conexión de comunicación entre Pico 2, Controlador del motor VNH5019 y el encoder del motor.
- Conexión vía Qwiic entre Pico 2 Plus y BNO085 y VL53L4CD. La forma más sencilla de conexión y nos liberó del uso de varios cables Dupont.
- Conexión vía USB entre RPI5 y LiDAR, conexión sugerida por el fabricante.
- Conexión vía cable FPC de 22-pin a 15-pin entre RPI5 y Cámara
- Se realizaron todas las conexiones para tener una tierra común del circuito eléctrico en una mini protoboard.

Para la conexión entre el Raspberry Pi 5 con el Pimoroni Pico 2 Plus y con el LiDAR, utilizamos cables USB a USB-C para transferencia de datos USB 3.1 que garantizan una velocidad de transmisión de 10 Gbps.

Detalle de Cableado

Alimentación principal (LiPo 3S)

Desde | Hacia | Cable
LiPo (+) | VNH5019 VIN | Rojo
LiPo (+) | D24V90F5 VIN | Rojo
LiPo (+) | D36V50F5 VIN | Rojo
LiPo (−) | GND común | Negro

VNH5019 (driver de motor)

Pin VNH5019 | Conectado a | Función
VIN | LiPo (+) | Alimentación de potencia (5.5–24 V)
GND (lado derecho) | GND común | Tierra
OUTA | Motor (+) cable rojo | Salida motor canal A
OUTB | Motor (−) cable negro | Salida motor canal B
INA | Pico GP9 | Control dirección A
INB | Pico GP8 | Control dirección B
PWM | Pico GP12 | Modulación velocidad
ENA / DIAGA | Pico GP10 | Diagnóstico canal A
ENB / DIAGB | Pico GP13 | Diagnóstico canal B
CS | (sin uso)
VDD | D24V90F5 5V | Alimentación lógica

Encoder del motor

Cable | Color | Conectado a
VCC | Azul | Pico Plus 2 pin 35 (3.3 V)
GND | Verde | Pico Plus 2 pin 3 (GND)
ENCA | Amarillo | Pico Plus 2 GP2
ENCB | Blanco | Pico Plus 2 GP3

Servo Savox SC-1251MG

Cable servo | Color | Conectado a
Signal | Amarillo | Pico Plus 2 GP15
V+ | Rojo | D36V50F5 VOut (5 V)
GND | Negro | D36V50F5 GND (uno de los 4)

Bus Qwiic (I²C) Pico → Sensores

Pico Plus 2 Qwiic conectado a SparkFun Qwiic MultiPort ─► BNO085 (IMU)
─► VL53L4CD #1 (ToF izquierdo) ─► VL53L4CD #2 (ToF derecho)

Bus USB (RPi 5)

Periférico | Puerto
Pico Plus 2 | USB-A del RPi 5 (cable USB-C 3.1 Gen2 corto, 6 in)
LiDAR STL-27L | USB-A del RPi 5 (vía adaptador CP2102 incluido)

Bus FPC (cámara)

Cable FPC 22-pin 0.5 mm → 15-pin 1 mm, 200 mm, conectado del puerto CSI-2 del RPi 5 al conector de la cámara Global Shutter.

Alimentación de la lógica (D24V90F5 5V)

Desde | Hacia | Pin RPi
D24V90F5 VOut (5 V) | RPi 5 pin 2 (5V) | GPIO header
D24V90F5 GND | RPi 5 pin 39 (GND) | GPIO header
(GND adicional) | RPi 5 pin 6 (GND) | a GND común

Botón de inicio

Pin botón | Conectado a
GND | Pico Plus 2 pin 32 (GND)
Signal | Pico Plus 2 pin 28 (GP) con pull-up interno

### 2.4 Fase 4: Programación, Pruebas e Iteración (Semanas 12-20)

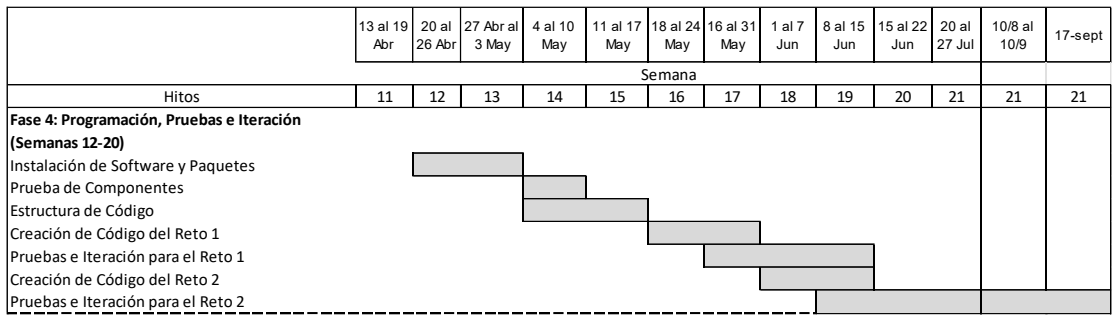
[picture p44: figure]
13 al 19 Abr; 20 al 26 Abr; 27 Abr al 3 May; 4 al 10 May; 11 al 17 May; 18 al 24 May; 16 al 31 May; 1 al 7 Jun; 8 al 15 Jun; 15 al 22 Jun; 20 al 27 Jul; 17-sept; Hitos; Instalación de Software y Paquetes Prueba de Componentes Estructura de Código Creación de Código del Reto 1 Pruebas e Iteración para el Reto 1 Creación de Código del Reto 2 Pruebas e Iteración para el Reto 2; Semana

Semanas 12 y 13: Instalación de Software y Paquetes

- Instalación en RPI5
- Ubuntu 24.04
- ROS 2
- Paquetes de Lidar, Sensores y Cámara

Setup del Raspberry PI 5

1. Bajar a PC/Laptop el Raspberry Pi Imager desde https://www.raspberrypi.com/software/
2. Insertar la MicroSD y correr el Raspberry Pi Imager, seleccionar el Sistema Operativo deseado que es el Ubuntu 24.04 Desktop (64-bit), luego pide la creación de usuario y clave, así como la configuración del WiFi, aunque esto se puede hacer después. Luego comienza a instalar en la Micro SD el Ubuntu 24.04.
3. Cuando termina de grabar, se introduce la Micro SD en la RPI5 y además lo más sencillo es conectarle un teclado, mouse y monitor, utilizando los puertos que la RPI 5 dispone.
4. Al encender la RPI5 se termina la configuración incluido, idioma, teclado, wifi y vuelve a pedir creación de Usuario y Password
5. Configuramos ahora el servidor SSH, para poder acceder a las RPI5 sin necesidad de estar siempre conectado a un monitor, teclado y mouse, sino via wifi desde una laptop. Esto es sumamente importante dado que la RPI va estar en el carro y será más sencillo para hacer pruebas.
6. Para configurar el SSH, se va al Terminal del sistema dentro del RPI y se colocan los comandos para actualización de paquetes y del servidor SSH

sudo apt update

sudo apt install openssh-server -y

7. Luego lo activamos para que esté disponible siempre que se use el robot

sudo systemctl enable ssh

Fase 4: Programación, Pruebas e Iteración (Semanas 12-20)

sudo systemctl start ssh

8. Buscamos el IP del RPI5 en la Red
- hostname -I en nuestro caso fue 192.168.68.54
9. En la Laptop ahora se busca el prompt del sistema y ahí se coloca
- ssh usuario@IP en nuestro caso ssh npc@192.168.68.54
- Pregunta la contraseña y aparece npc@npc:-$, ya no que está conectado dentro del laptop si no a la RPI 5. En nuestro caso aparece: npc@npc:-$

Agregar los repositorios de ROS 2

bash
sudo apt install software-properties-common sudo add-apt-repository universe
bash
sudo apt update && sudo apt install curl -y

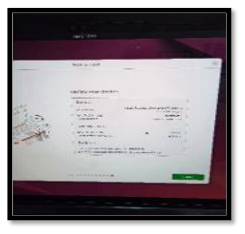
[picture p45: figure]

sudo curl -sSL https://raw.githubusercontent.com/ros/rosdistro/master/ros.key -o /usr/share/keyrings/ros-archive-keyring.gpg
bash
echo "deb [arch=$(dpkg --print-architecture) signed-by=/usr/share/keyrings/ros-archive-keyring.gpg] http://packages.ros.org/ros2/ubuntu $(. /etc/os-release && echo
$UBUNTU_CODENAME) main" | sudo tee /etc/apt/sources.list.d/ros2.list > /dev/null

Instalar ROS 2 Jazzy
bash
sudo apt update
sudo apt upgrade -y
bash
sudo apt install ros-jazzy-ros-base -y Esto tarda unos minutos.

Configurar el entorno
bash
echo "source /opt/ros/jazzy/setup.bash" >> ~/.bashrc source ~/.bashrc

Instalar herramientas adicionales
bash
sudo apt install python3-colcon-common-extensions python3-rosdep -y sudo rosdep init
rosdep update
- Instalación en Laptop
- Ubuntu 24.04
- Setup de Conexión de RPI5 por SSH
- ROS 2
- Rivz2
- Arduino IDE
- Visual Code

Instalación de Ubuntu y ROS 2

La instalación de Ubuntu y ROS2 en la laptop es similar a la de la RPI. Nosotros usamos una partición de disco distinta para tener el Ubuntu separada totalmente de Windows y utilizamos la versión de Server.

Setup de Conexión de RPI5 por SSH

Ubuntu Server 24.04 ya trae openssh-server activo, pero verificar con sudo systemctl status ssh. Si no estuviera:

sudo apt install openssh-server y sudo systemctl enable --now ssh.

Busqueda de IP estable
hostname -I en el Pi para conocer la dirección. Lo puedes buscar también en la Red donde se está configurando la dirección MAC.

Para poner conectarte desde la laptop deberás colocar en el Terminal
ssh usuario@192.168.68.x → contraseña.

RViz2 (Visualización de Sensores)

Para ver lo que el Lidar detecta o lo que la cámara. ROS 2 permite que la RPI envíe solo los datos procesados a la laptop. Tú abres un programa llamado RViz2 en tu laptop y ahí verás el mapa y los obstáculos en 3D sin sobrecargar la Raspberry Pi.

Este programa debe correr directamente en la laptop (no por SSH).

- Su función: Como ROS 2 es un sistema distribuido, la Raspberry Pi "transmite" los datos del Lidar y del IMU por el Wi-Fi, y RViz2 en tu laptop los recibe y los dibuja.

Para instalarlo en la laptop luego de tener Ubuntu y ROS2 instalados:

export RMW_IMPLEMENTATION=rmw_cyclonedds_cpp export ROS_DOMAIN_ID=<el mismo número en Pi y laptop>

Arduino IDE

1. Descargar el archivo:
- Entra al sitio web oficial de Arduino IDE

https://support.arduino.cc/hc/en-us/articles/360019833020-Download-and-install-Arduino-IDE

- Busca la sección para Linux y descarga la versión de 64 bits en formato AppImage.
2. Ejecutar el programa:
- Haz doble clic en el archivo .AppImage o haz clic derecho y selecciona Ejecutar para abrir el IDE de Arduino.
3. Configurar permisos para la placa USB:
- Para que tu computadora reconozca la placa Arduino por el puerto serie sin usar comandos de administrador, añade tu usuario al grupo dialout:

bash
sudo adduser $USER dialout

Visual Code

1. Abre tu navegador y ve a la Página oficial de descargas de VS Code.

https://code.visualstudio.com/docs/setup/linux

2. Haz clic en el botón .deb (para Debian/Ubuntu) para descargar el instalador.
3. Abre la terminal y dirígete a tu carpeta de descargas:

bash
cd ~/Descargas

Instala el paquete ejecutando el siguiente comando:

bash
sudo apt install ./code_*.deb

Semana 14: Prueba de Componentes

- Pruebas de Conexión RPI5-Laptop a través de protocolo SSH conectando ambos dispositivos a la misma red y la conexión efectiva abriendo un terminal de RPI5 desde la Laptop.

- Pruebas de Conexión RPI5-Pico 2 Plus, conectada la Pico 2 a el puerto /dev/ttyACM0, utilizamos pyserial para confirmar la comunicación entre ambos controladores.
- Pruebas de LiDAR, conectando a la RPI 5 bajo el puerto /dev/ttyUSB0 y ejecutando en la terminal el nodo de ROS 2 correspondiente al LiDAR, encargado de leer los datos de distancia por del tópico de tipo /scan. Finalmente, se lanza RViz2 en el entorno de la Laptop para visualizar la nube de puntos marcada por el LiDAR
- Pruebas de Cámara. Vista y configuración de colores y poder evidenciar los tópicos
- Realización de Pruebas de IMU BNO085, Motor, Encoder y Servo

Realizamos un Test integral para ver que todo funcione sin problema y en el sentido correcto.

El Test está en la carpeta de SRC (Test de Robot.py, pero en todo caso so queríamos mover el motor 2 segundos en cada dirección mover el servo y la medición de las variables del IU y del encoder.

Luego de varias pruebas y anotar algunas convenciones de derecha e izquierda, pasamos al siguiente punto. Estas pruebas las repetimos varias veces en alguna ocasión cuando el código no lográbamos hacer lo que queríamos y así descartábamos algún mal funcionamiento.

Semana 14 y 15 Estructura de Código

Dado que el Pimoroni Pico 2 Plus, como microcontrolador, lo designamos encargado de la gestión en tiempo real de los motores, sensores Encoder, TOF e IMU, debe por una parte proveer de toda la lectura de información al Raspberry Pi 5, que junto con la información que el recopila de la Cámara y el LiDAR pueda tomar decisión en base al código o estrategia suministrada. Esas decisiones por otra parte deben ser transmitidas al Raspberry Pico 2 Plus para accionar.

En base a lo anterior decidimos elaborar un código en Arduino .ino que realiza las mediciones de los sensores y transmite al Raspberry Pi 5. Dado que decidimos trabajar con ROS2 y manejarlos a través de nodos y tópicos, era necesario un código bridge en Python que hicieran legible el código ejecutado en Arduino IDE tanto de salida al RPI5 como de entrada de las instrucciones a los motores.

Finalmente, el control de las instrucciones y estrategia de abordaje del reto debía estar en Python desde donde recibía la información y mandaba al nodo bridge para comunicarse con el Pico 2 Plus, pero también recibía la información de los tópicos creados para la información de la Camara y el Lidar.

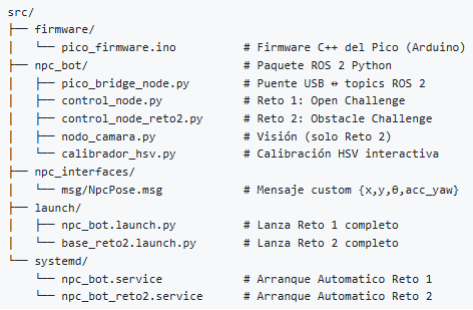
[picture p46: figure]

Firmware del Pico 2

El Pico Plus 2 ejecuta un firmware basado en Arduino (pico_firmware.ino) que maneja todas las operaciones de tiempo real de las que la RPi5 no debe encargarse.

- Lectura del IMU a 100 Hz vía Qwiic I2C (Adafruit BNO085, con fusión sensorial 9-DOF onboard)
- Conteo del encoder vía interrupción por hardware en GPIO 2 (Canal A) y lectura digital en GPIO 3 (Canal B), cuadratura de un solo flanco
- Integración de odometría a 100 Hz (calcula Δx, Δy, Δtheta y los acumula)
- Generación de PWM del motor a 20 kHz (sobre el rango audible) vía driver Pololu VNH5019
- Generación de PWM del servo a 50 Hz para el servo de dirección Savox SC-1251MG
- Lectura del botón de arranque en GPIO 28 (INPUT_PULLUP, activo LOW)
- Publicación de telemetría a la Pi5 a 50 Hz vía USB serial

Protocolo Serial de Comunicación RPi5 y Pico2

Pico → Pi5 (50 Hz cada uno):

POS <x, y, theta, acc_yaw> → Odometría IMU <yaw, qx, qy, qz> → Quaternión del IMU ENC < ticks > → Conteo del encoder BTN → Botón presionado (evento) BOOT,... OK,... ERR,... → Mensajes de estado
Pi5 → Pico (a demanda):

M < velocidad_ms > → Velocidad del motor en m/s S < direccion > → Servo, rango [-1.0, +1.0] STOP → Parada de emergencia

Tópicos

Se desarrolló un esquema de comunicación basado en tópicos, estableciendo los nodos suscriptores y publicador fundamental para la comunicación en ROS2.

Topico | Tipo | Publicador | Suscriptor | Descripción
/scan | sensor_msgs/LaserScan | Driver LiDAR | control_node | Scan LiDAR 360° @10 Hz
/npcpos | npc_interfaces/NpcPose | pico_bridge | control_node | Pose del robot (x, y, theta, acc_yaw) @50 Hz
/start | std_msgs/Empty | pico_bridge | control_node | Señal de inicio (botón)
/cmd_motor | std_msgs/Float32 | control_node | pico_bridge | Velocidad del motor en m/s
/cmd_servo | std_msgs/Float32 | control_node | pico_bridge | Dirección en [-1.0, +1.0]
/imu | sensor_msgs/Imu | pico_bridge | (debug) | Datos del IMU filtrados
/encoder | std_msgs/Int32 | pico_bridge | (debug) | Ticks crudos del encoder

Semana 16 y 17 Creación de Código del Reto 1

La estrategia para el reto 1 (sin obstáculos) no visionábamos que fuera muy distinta a la que utilizamos en 2025. El robot debe detectar cuándo ha llegado a una esquina, decidir hacia qué lado girar, y en qué sentido (CW o CCW) seguirá toda la carrera. La diferencia es que en 2025 lo hicimos con ultrasónicos y ahora contamos con un LiDAR, esto nos permitió hacer la detección de una forma más robusta.

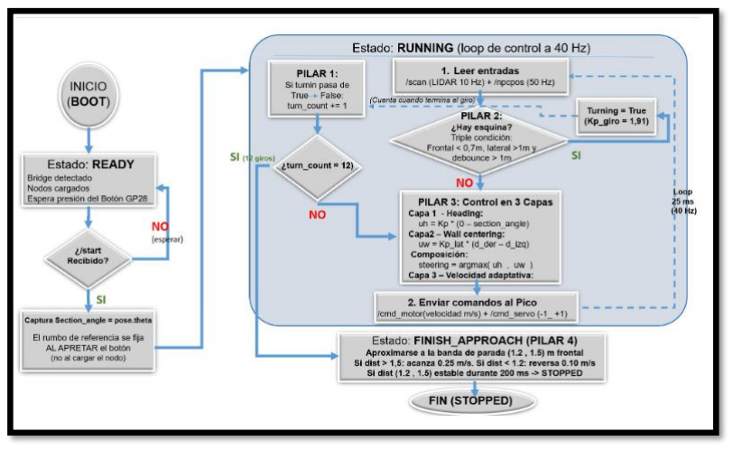
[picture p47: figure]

Al encontrarnos a 0,7 metros de la pared central, el LiDAR revisa los laterales en busca de aperturas (lecturas mayores a 1m). Sin embargo, no dependimos de una medida única frontal del LiDAR y 2 laterales, le pedimos la mediana de ±5° de la medición frontal y 2° de mediciones laterales en vez de solo una medición a +75° y -75°. En el caso de nuestro LiDAR que nos da 2.160 mediciones en cada vuelta, esto representa 6 mediciones por cada grado, permitiéndonos tener 60 mediciones frontales (10x6) y 12 en cada lateral (2x6), dando más robustez y evitar falsas señales.

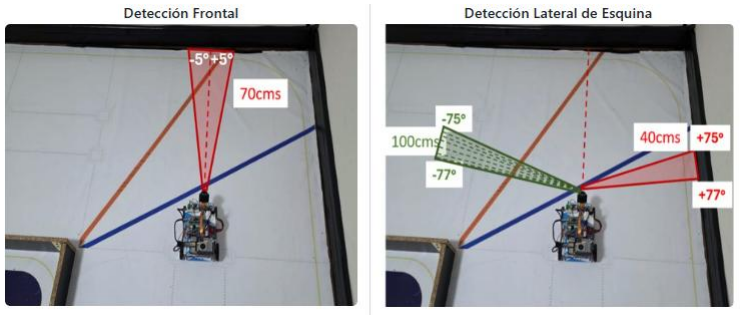
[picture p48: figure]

Luego de la detección de la apertura se activa el giro y lo mas importante es determinar hasta cuando debe girar el robot. El año pasado estuvimos muy limitados por que tuvimos problema para hacer funcionar el IMU. Este año con el BNO085 conectado a la Pico Plus 2 tuvimos resuelto, siendo la función del IMU indicar cuando habíamos logrado alcanzar 90 grados adicionales, por lo que no importaba si el robot llegaba con cierto desvío a la esquina, porque el IMU le iba a indicar al robot que debía girar hasta lograr la posición objetivo (+90 grados en cada esquina).

No obstante, para hacer la tarea mas sencilla, mantuvimos un sistema de ajuste para que mientras el robot no estuviera girando porque estaba en una recta, tratará de mantenerse lo mas centrado posible, para eso, usamos mediciones laterales de cada lado del LiDAR que mandan a realizar ajustes en la dirección dependiendo de la diferencia entre la distancia a la pared derecha – la distancia a la pared izquierda.

pos = dist_der - dist_izq
str_lateral = clamp(pos * KP_LATERAL, -0.5, +0.5)

Finalmente, para garantizar culminar en el segmento que comenzó el robot luego de las 3 vueltas, se configuró una estrategia que después de 12 giros, el robot continuara adelante a una velocidad reducida y parara cuando estuviera a 1,5 m de la pared frontal. Lo que garantizaba parar en el centro de la sección.

Para mayor detalle de las líneas de comando principales se puede ver el segmento 6 del Readme y para ver el código con anotaciones se pueden obtener los archivos en la carpeta /SRC del Github, estando el código principal del reto 1 en el archivo control_node.py

Semana 17 a 19: Pruebas e Iteración para el Reto 1

Desde el comienzo los resultados de las pruebas fueron bastante positivos, con varias iteraciones sobre todo en ajustar velocidad y otros parámetros como agresividad del giro, distancia ideal para activar la detección de apertura, considerando que las condiciones del centro de la pista pudiera ser variables.

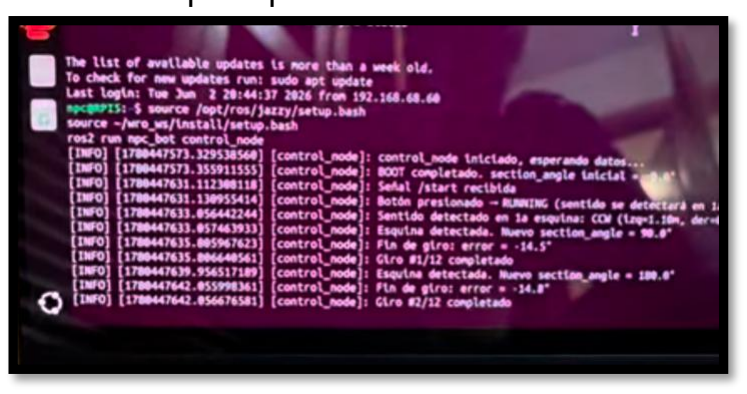
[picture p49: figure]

Al final como equipo dimos mas peso a ser confiables que a lograr menores tiempo, por lo que, pese a que en ocasiones lográbamos bajar los tiempos de 70 segundos a 64 segundos y finalmente a 55 seg, este último no era totalmente libre de errores.

Métricas de Desempeño Reto 1.

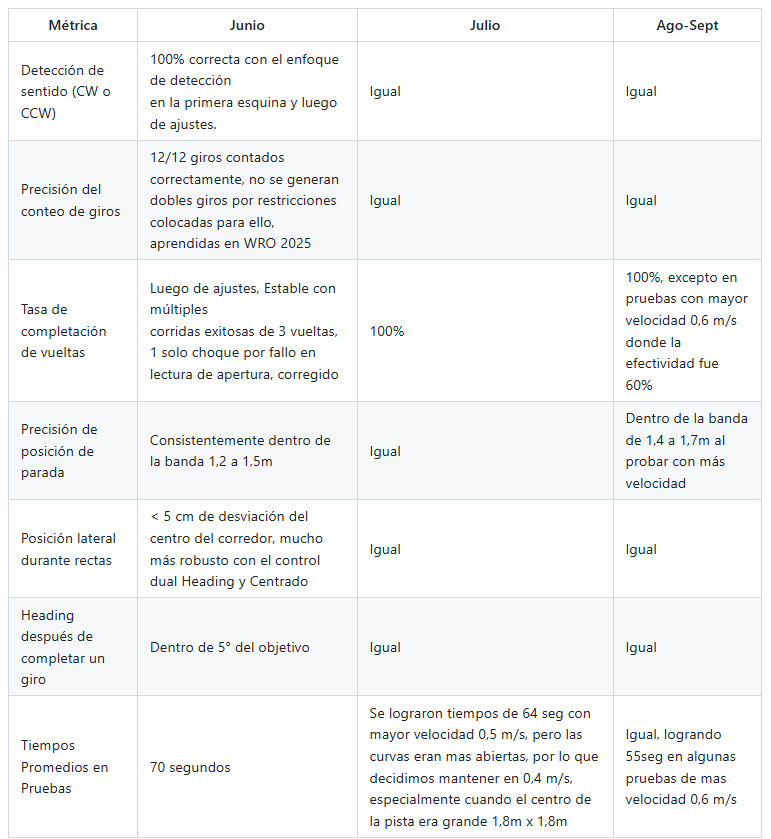
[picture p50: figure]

Semana 18 a 19: Creación de Código del Reto 2

Fue nuestro dolor de cabeza de 2025 y nuestro gran reto para 206, con la confianza que tenemos un robot más robusto y tecnológicamente avanzado, además de contar con 1 año más de experiencia. El sistema de navegación del reto 1 no funcionaría en el reto 2, la detección de aperturas podía estar condicionado a que un obstáculo limitara la detección de una apertura.

En nuestra investigación vimos que muchos equipos se valían de mapear el camino y generar un mapa de la pista conforme avanzaban. Sin embargo, para nosotros la vía correcta era tener un robot que fuera de manera autónomamente así la pista cambiara, es decir, que incluso pudiera navegar fuera de la pista, tal como lo hace un humano con su vista, donde de alguna manera en un camino buscas la apertura que se va generando o visto de otra manera la ruta mas profunda sin interrupción.

Para traducir esto al robot, el LiDAR debía reportar un abanico de direcciones candidatas frente al robot (de −60° a +60° en intervalos de 2° - 60 lecturas) y cada una se convierte en una "Ruta Viable", entonces para cada una se calcula un "score" para determinar cual es la trayectoria ideal o best_dir. Ese score combina 2 cosas, 1) Cuán lejos puede ir el robot en esa dirección sin chocar con algo y 2) Que tan desviada está esa dirección respecto al rumbo objetivo de la pista. La dirección ganadora es la propuesta inicial de hacia dónde dirigirse.

Adicionalmente para cada una de las 60 rutas candidatas, se aplica el principio de "ray marching" donde no solo se observa el punto candidato, sino que también se mide un radio de 7,5 cm de cada lado para cerciorarnos que el robot pueda caber por esa ruta, si en la ruta candidata se choca con algún objeto al ver el ray marching, entonces esa ruta es descartada o su distancia máxima se limita hasta donde si cabe el ray marching.

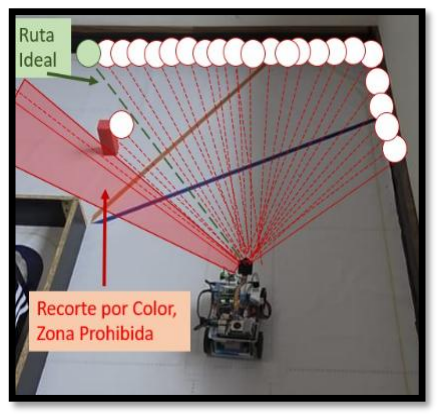
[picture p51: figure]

Esto garantizaría que, sin obstáculos en la pista,
el robot siempre seguirá la ruta más profunda y
pudiera hacer el reto 1 sin problema, pero con
una lógica de navegación diferente, no hay esquinas, solo se sigue la ruta mas profunda.

Para poder manejar los obstáculos la lógica que se nos ocurrió fue que el robot siguiera buscando la ruta más profunda, pero en presencia de un obstáculo, limitara las rutas a las que estaban por el lado que debe pasar el robot, es decir, si el pilar era rojo, todas las rutas a la izquierda del pilar estuvieran eliminadas de las candidatas y el robot solo podía elegir entre aquellas que garantizaba que pasaban por el lado correcto. Al pasar el pilar, se eliminaba la restricción hasta la detección del nuevo pilar.

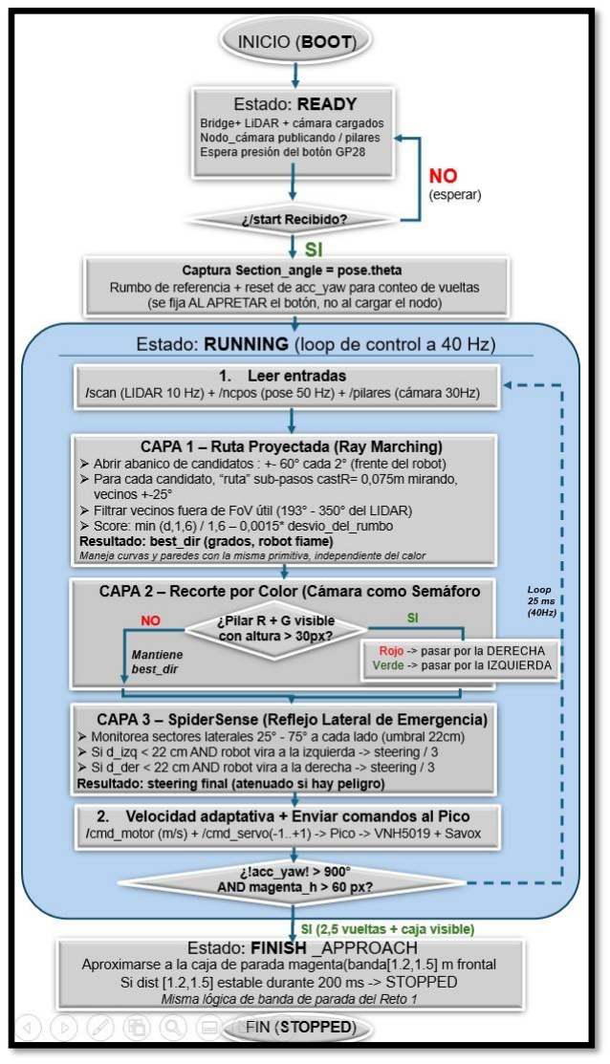
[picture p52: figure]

Para mayor detalle de las líneas de comando principales se puede ver el segmento 6 del Readme y para ver el código con anotaciones se pueden obtener los archivos en la carpeta /SRC del Github, estando el código principal del reto 1 en el archivo control_node_reto2.py

Semana 19 a 21: Pruebas e Iteración para el Reto 2

Si bien pensamos que la estrategia para el Reto 2 es la correcta, lograr la combinación ideal de los valores de
los parámetros ha sido una labor muy iterativa. Hemos tratado de balancear entre el nivel de velocidad correcto para dar el mayor tiempo de detección temprana a la cámara y al robot de capacidad de respuesta para buscar la ruta ideal que nos lleve a la evasión de los pilares. No obstante, lo pronunciado del giro y el tamaño del Ray Marching para evitar choques laterales del robot ha sido el verdadero reto.

A esto se incorpora otro elemento que es la tonalidad cambiante de los colores dependiendo del nivel de luz y si este es natural o de lamparas, así como que puede cambiar dependiendo en la sección de la pista que se encuentre el robot. Para esto hemos tratado una combinación de códigos para cada color lo suficiente amplia para que no sea tan sensible, sin embargo,
estamos consientes que ajustes el día de la
competencia, ya en pista serán necesarios.

A continuación, reportamos los avances con la métricas de desempeño del Reto con Obstáculos.

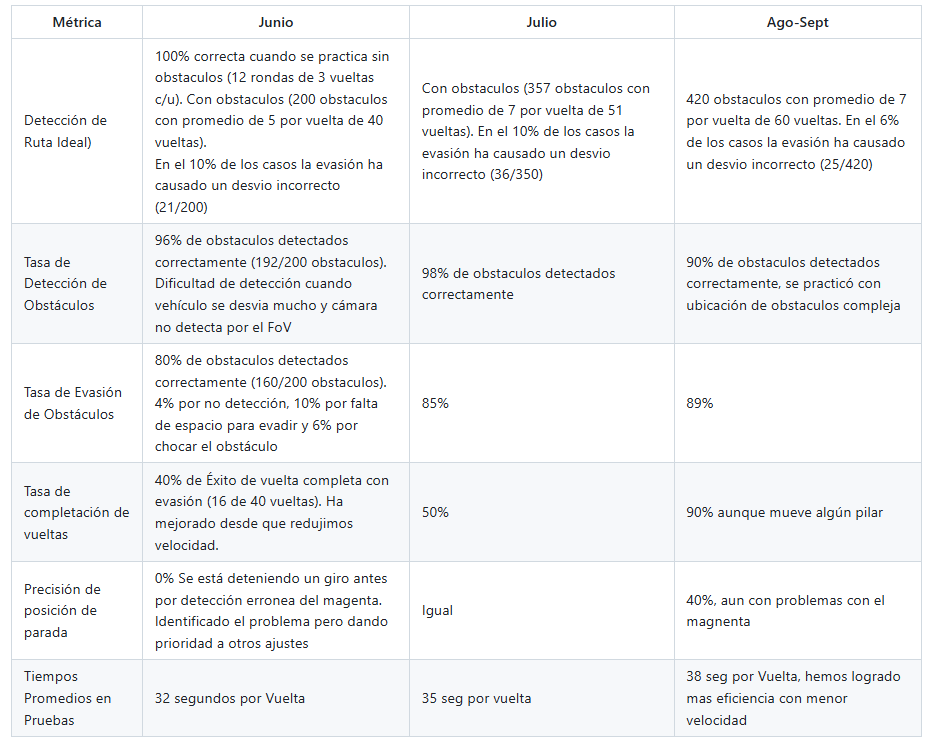
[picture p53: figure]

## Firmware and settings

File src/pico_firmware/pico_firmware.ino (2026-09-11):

/* ============================================================
 *  pico_firmware.ino
 *  ------------------------------------------------------------
 *  Firmware para la Pico Plus 2 (RP2350) de Proyecto Mahoraga
 *  Reto Abierto (Reto 1) — Equipo NPC
 *
 *  Que hace?:
 *    1. Leer encoder del motor por interrupciones
 *    2. Leer IMU BNO085 por I2C (Qwiic)
 *    3. Calcular odometría (x, y, theta, acc_yaw) a 100 Hz
 *    4. Recibir comandos seriales (M, S, STOP) por USB CDC
 *    5. Generar PWM para motor (VNH5019) y servo (Savox SC-1251MG)
 *    6. Publicar telemetría a 50 Hz por USB CDC
 *
 *  Protocolo serial (todos los mensajes terminan en '\n'):
 *    Pico → Pi5:
 *      POS,x,y,theta,acc_yaw    (posición + yaw acumulado sin wrap)
 *      IMU,yaw,qx,qy,qz         (yaw actual + cuaternión)
 *      ENC,ticks                (ticks crudos del encoder)
 *      BTN                      (botón físico presionado)
 *      OK                       (confirmación de comando)
 *      ERR,mensaje              (error o comando no reconocido)
 *    Pi5 → Pico:
 *      M,velocidad              (m/s, ej: M,0.80 o M,-0.20)
 *      S,steering               (-1.0 a +1.0, ej: S,-0.25)
 *      STOP                     (parada de emergencia)
 *
 *  Conexiones de hardware:
 *    Motor VNH5019:
 *      GPIO  8 → INB (dirección B)
 *      GPIO  9 → INA (dirección A)
 *      GPIO 10 → ENA (enable A, mantener HIGH)
 *      GPIO 12 → PWM (velocidad, 20 kHz)
 *      GPIO 13 → ENB (enable B, mantener HIGH)
 *    Servo Savox SC-1251MG:
 *      GPIO 15 → señal PWM (50 Hz, rango 15° a 165°, centro 90°)
 *    Encoder motor (48 CPR + reducción 34:1):
 *      GPIO  2 → Canal A (interrupción RISING)
 *      GPIO  3 → Canal B (lectura digital para sentido)
 *    Botón de arranque (pulsador a GND):
 *      GPIO 28 → señal del botón (INPUT_PULLUP, activo LOW)
 *    IMU BNO085 (Adafruit, Qwiic):
 *      GPIO  4 → SDA (I2C0)
 *      GPIO  5 → SCL (I2C0)
 *      Dirección I2C: autodetectada por la librería (0x4A o 0x4B)
 *    USB-C → Raspberry Pi 5 (Serial CDC, 921600 baud)
 * ============================================================ */

#include <Wire.h>
#include <Adafruit_BNO08x.h>

/* ============================================================
 *  CONSTANTES Y VARIABLES PARAMETRIZABLES
 * ============================================================ */

// --- Pines ---
constexpr uint8_t PIN_MOTOR_INA  = 9;
constexpr uint8_t PIN_MOTOR_INB  = 8;
constexpr uint8_t PIN_MOTOR_PWM  = 12;
constexpr uint8_t PIN_MOTOR_ENA  = 10;
constexpr uint8_t PIN_MOTOR_ENB  = 13;
constexpr uint8_t PIN_SERVO      = 15;
constexpr uint8_t PIN_ENCODER_A  = 2;
constexpr uint8_t PIN_ENCODER_B  = 3;
constexpr uint8_t PIN_BOTON      = 28;

// --- Comunicación ---
constexpr unsigned long SERIAL_BAUD = 921600;

// --- Motor (VNH5019) ---
constexpr int  PWM_FREQ_MOTOR    = 20000;   // 20 kHz, ultrasónico (sin ruido audible)
constexpr int  PWM_RESOLUTION    = 255;     // analogWrite estándar Arduino
// Valor calibrado empíricamente en pista:
//   Pedida 0.5 m/s con MS_TO_PWM=200 → tiempo en 2m: 5.05s y 4.80s
//   Velocidad real promedio: 0.406 m/s
//   Ajuste: 200 × (0.5 / 0.406) = 246
constexpr float MS_TO_PWM        = 246.0;   // ajustar si pruebas lo justifican
constexpr float MAX_VELOCITY_MS  = 1.20;    // máx velocidad permitida, aunque no hemos pasado de 0,7

// --- Servo (Savox SC-1251MG) ---
constexpr int SERVO_CENTER_DEG   = 90;      // centro físico
constexpr int SERVO_MIN_DEG      = 15;      // tope izquierdo permitido
constexpr int SERVO_MAX_DEG      = 165;     // tope derecho permitido
// El rango útil simétrico desde el centro es ±75° (90→15 y 90→165)
constexpr int SERVO_HALF_RANGE   = 75;

// --- Encoder ---
// Valor calibrado empíricamente:
//   Robot empujado 1.0 m → ENC delta promedio: 2007 ticks

constexpr float TICKS_POR_METRO  = 2007.0;

// --- Loops y frecuencias ---
constexpr unsigned long LOOP_ODOM_INTERVAL_US    = 10000;   // 100 Hz (cálculo odometría)
constexpr unsigned long LOOP_PUBLISH_INTERVAL_US = 20000;   // 50 Hz (envío telemetría)

// --- Botón ---
constexpr unsigned long BOTON_DEBOUNCE_MS = 50;             // tiempo mínimo entre detecciones

/* ============================================================
 *  VARIABLES GLOBALES
 * ============================================================ */

// --- IMU ---
Adafruit_BNO08x bno;
sh2_SensorValue_t sensorValue;
float yaw_rad   = 0.0;     // yaw actual normalizado a [-pi, +pi]
float qx = 0.0, qy = 0.0, qz = 0.0, qw = 1.0;  // cuaternión actual
bool  imu_ready = false;

// --- Encoder (volatile porque se modifican en ISR) ---
volatile long encoder_ticks = 0;
long          encoder_ticks_prev = 0;

// --- Odometría ---
float pos_x      = 0.0;    // posición x en metros (relativa al arranque)
float pos_y      = 0.0;    // posición y en metros
float pos_theta  = 0.0;    // orientación actual (igual a yaw_rad)
float acc_yaw    = 0.0;    // yaw acumulado SIN wrap (para contar giros desde Pi5)
float yaw_prev   = 0.0;    // yaw del loop anterior (para detectar wrap)
bool  yaw_initialized = false;

// --- Comandos recibidos ---
float cmd_velocity = 0.0;  // m/s (positivo adelante, negativo atrás)
float cmd_steering = 0.0;  // -1.0 (izquierda max) a +1.0 (derecha max)

// --- Botón ---
bool          boton_anterior = HIGH;       // último estado leído (HIGH = no presionado)
unsigned long t_ultima_deteccion_boton = 0; // timestamp ms del último BTN enviado

// --- Timers ---
unsigned long t_last_odom    = 0;
unsigned long t_last_publish = 0;

// --- Buffer para parsing serial ---
String serial_buffer = "";

/* ============================================================
 *  ISR DEL ENCODER (Interrupción de hardware)
 *  Se ejecuta cada vez que el canal A tiene flanco de subida.
 *  El signo se ajustó (++/--) para que ticks positivos
 *  correspondan a avance hacia adelante del robot.
 * ============================================================ */
void encoderISR() {
  if (digitalRead(PIN_ENCODER_B) == LOW) {
    encoder_ticks--;
  } else {
    encoder_ticks++;
  }
}

/* ============================================================
 *  SETUP
 * ============================================================ */
void setup() {
  // --- Serial USB ---
  Serial.begin(SERIAL_BAUD);
  // Esperamos opcionalmente al puerto serial (hasta 2 segundos)
  unsigned long t0 = millis();
  while (!Serial && (millis() - t0) < 2000) { delay(10); }
  Serial.println("BOOT,pico_firmware v1.0");

  // --- Pines del motor ---
  pinMode(PIN_MOTOR_INA, OUTPUT);
  pinMode(PIN_MOTOR_INB, OUTPUT);
  pinMode(PIN_MOTOR_ENA, OUTPUT);
  pinMode(PIN_MOTOR_ENB, OUTPUT);
  pinMode(PIN_MOTOR_PWM, OUTPUT);
  digitalWrite(PIN_MOTOR_ENA, HIGH);     // habilitar driver lado A
  digitalWrite(PIN_MOTOR_ENB, HIGH);     // habilitar driver lado B
  digitalWrite(PIN_MOTOR_INA, LOW);
  digitalWrite(PIN_MOTOR_INB, LOW);

  // Frecuencia PWM del motor (RP2350 en Arduino IDE de Earle Philhower)
  analogWriteFreq(PWM_FREQ_MOTOR);       // 20 kHz
  analogWriteResolution(8);              // 8 bits → 0-255
  analogWrite(PIN_MOTOR_PWM, 0);

  // --- Servo (usamos PWM manual a 50 Hz) ---
  // En Earle Philhower, podemos usar la librería Servo.
  // Para máxima portabilidad usamos la librería Servo estándar.
  setupServo();

  // --- Encoder con interrupciones ---
  pinMode(PIN_ENCODER_A, INPUT_PULLUP);
  pinMode(PIN_ENCODER_B, INPUT_PULLUP);
  attachInterrupt(digitalPinToInterrupt(PIN_ENCODER_A), encoderISR, RISING);

  // --- Botón de arranque ---
  // INPUT_PULLUP: resistencia interna activada
  // El botón conecta a GND, por lo tanto presionado = LOW
  pinMode(PIN_BOTON, INPUT_PULLUP);
  boton_anterior = digitalRead(PIN_BOTON);

  // --- IMU BNO085 por I2C (Qwiic = I2C0 en GPIO 4/5) ---
  Wire.setSDA(4);
  Wire.setSCL(5);
  Wire.begin();
  if (bno.begin_I2C()) {
    imu_ready = true;
    // Activar reporte de Game Rotation Vector (cuaternión sin magnetómetro)
    // a 100 Hz (10 ms entre muestras)
    bno.enableReport(SH2_GAME_ROTATION_VECTOR, 10000);
    Serial.println("OK,IMU iniciado");
  } else {
    Serial.println("ERR,IMU no detectado en bus I2C");
  }

  // --- Inicializar timers ---
  t_last_odom    = micros();
  t_last_publish = micros();

  Serial.println("OK,setup completo");
}

/* ============================================================
 *  SETUP DEL SERVO
 *  Usamos la librería Servo estándar de Arduino, que en RP2350
 * ============================================================ */
#include <Servo.h>
Servo servo;

void setupServo() {
  servo.attach(PIN_SERVO, 1000, 2000);   // 1000-2000 us típico para servos hobby
  servo.write(SERVO_CENTER_DEG);          // centrar al inicio
}

/* ============================================================
 *  LOOP PRINCIPAL
 *  No usamos delay(). Tres tareas concurrentes:
 *    - Lectura IMU + odometría (100 Hz)
 *    - Publicación de telemetría (50 Hz)
 *    - Procesamiento de comandos seriales (continuo)
 * ============================================================ */
void loop() {
  unsigned long now = micros();

  // --- 1. Procesar comandos seriales (cada iteración) ---
  procesarSerial();

  // --- 2. Verificar botón físico (cada iteración) ---
  verificarBoton();

  // --- 3. Loop de odometría a 100 Hz ---
  if ((now - t_last_odom) >= LOOP_ODOM_INTERVAL_US) {
    t_last_odom = now;
    actualizarIMU();
    actualizarOdometria();
  }

  // --- 4. Publicación de telemetría a 50 Hz ---
  if ((now - t_last_publish) >= LOOP_PUBLISH_INTERVAL_US) {
    t_last_publish = now;
    publicarTelemetria();
  }
}

/* ============================================================
 *  ACTUALIZAR IMU
 *  Lee del BNO085 si hay nuevos datos disponibles. Extrae
 *  el cuaternión y calcula yaw en radianes.
 * ============================================================ */
void actualizarIMU() {
  if (!imu_ready) return;

  // Procesa eventos pendientes; puede no haber datos nuevos en cada llamada
  if (bno.getSensorEvent(&sensorValue)) {
    if (sensorValue.sensorId == SH2_GAME_ROTATION_VECTOR) {
      qx = sensorValue.un.gameRotationVector.i;
      qy = sensorValue.un.gameRotationVector.j;
      qz = sensorValue.un.gameRotationVector.k;
      qw = sensorValue.un.gameRotationVector.real;

      // Convertir cuaternión a yaw (rotación alrededor del eje Z)
      // Fórmula estándar: yaw = atan2(2(qw*qz + qx*qy), 1 - 2(qy² + qz²))
      float siny_cosp = 2.0 * (qw * qz + qx * qy);
      float cosy_cosp = 1.0 - 2.0 * (qy * qy + qz * qz);
      yaw_rad = atan2(siny_cosp, cosy_cosp);
    }
  }
}

/* ============================================================
 *  VERIFICAR BOTÓN
 *  Detecta bajada (HIGH→LOW) que indica presión.
 *  Aplica debounce simple: ignora nuevas presiones durante
 *  BOTON_DEBOUNCE_MS milisegundos.
 * ============================================================ */
void verificarBoton() {
  bool boton_actual = digitalRead(PIN_BOTON);
  unsigned long ahora_ms = millis();

  // Detectar bajada (HIGH → LOW = botón recién presionado)
  if (boton_anterior == HIGH && boton_actual == LOW) {
    // Verificar debounce temporal
    if ((ahora_ms - t_ultima_deteccion_boton) > BOTON_DEBOUNCE_MS) {
      Serial.println("BTN");
      t_ultima_deteccion_boton = ahora_ms;
    }
  }
  boton_anterior = boton_actual;
}

/* ============================================================
 *  ACTUALIZAR ODOMETRÍA
 *  Combina ticks del encoder con yaw del IMU para calcular
 *  posición global (x, y, theta).
 *  Mantiene acc_yaw sin wrap para contar giros desde Pi5.
 * ============================================================ */
void actualizarOdometria() {
  // 1. Leer ticks acumulados de forma atómica (volatile)
  noInterrupts();
  long ticks_now = encoder_ticks;
  interrupts();

  // 2. Calcular distancia recorrida desde la última lectura
  long delta_ticks = ticks_now - encoder_ticks_prev;
  encoder_ticks_prev = ticks_now;
  float delta_s = (float)delta_ticks / TICKS_POR_METRO;

  // 3. Actualizar posición usando el yaw ACTUAL como dirección de avance
  pos_x += delta_s * cos(yaw_rad);
  pos_y += delta_s * sin(yaw_rad);
  pos_theta = yaw_rad;

  // 4. Acumular yaw sin wrap (para contar giros en Pi5)
  if (!yaw_initialized) {
    yaw_prev = yaw_rad;
    yaw_initialized = true;
  } else {
    float delta_yaw = yaw_rad - yaw_prev;
    // Corregir el "salto" cuando cruza ±pi (wrap-around)
    if (delta_yaw >  PI) delta_yaw -= 2.0 * PI;
    if (delta_yaw < -PI) delta_yaw += 2.0 * PI;
    acc_yaw += delta_yaw;
    yaw_prev = yaw_rad;
  }
}

/* ============================================================
 *  PUBLICAR TELEMETRÍA
 *  Envía POS, IMU y ENC por Serial en formato CSV.
 * ============================================================ */
void publicarTelemetria() {
  // POS,x,y,theta,acc_yaw
  Serial.print("POS,");
  Serial.print(pos_x, 4);
  Serial.print(",");
  Serial.print(pos_y, 4);
  Serial.print(",");
  Serial.print(pos_theta, 4);
  Serial.print(",");
  Serial.println(acc_yaw, 4);

  // IMU,yaw,qx,qy,qz
  Serial.print("IMU,");
  Serial.print(yaw_rad, 4);
  Serial.print(",");
  Serial.print(qx, 4);
  Serial.print(",");
  Serial.print(qy, 4);
  Serial.print(",");
  Serial.println(qz, 4);

  // ENC,ticks
  Serial.print("ENC,");
  Serial.println(encoder_ticks);
}

/* ============================================================
 *  PROCESAR SERIAL
 *  Lee bytes disponibles, arma mensajes terminados en '\n'
 *  y los parsea.
 * ============================================================ */
void procesarSerial() {
  while (Serial.available() > 0) {
    char c = Serial.read();
    if (c == '\n') {
      parsearComando(serial_buffer);
      serial_buffer = "";
    } else if (c != '\r') {
      serial_buffer += c;
      // Protección contra mensajes demasiado largos
      if (serial_buffer.length() > 64) {
        serial_buffer = "";
        Serial.println("ERR,buffer overflow");
      }
    }
  }
}

/* ============================================================
 *  PARSEAR COMANDO
 *  Reconoce: M,velocidad / S,steering / STOP
 * ============================================================ */
void parsearComando(String cmd) {
  cmd.trim();
  if (cmd.length() == 0) return;

  if (cmd.startsWith("M,")) {
    float v = cmd.substring(2).toFloat();
    // Limitar al rango permitido
    if (v >  MAX_VELOCITY_MS) v =  MAX_VELOCITY_MS;
    if (v < -MAX_VELOCITY_MS) v = -MAX_VELOCITY_MS;
    cmd_velocity = v;
    aplicarMotor(cmd_velocity);
    Serial.println("OK");
  }
  else if (cmd.startsWith("S,")) {
    float s = cmd.substring(2).toFloat();
    if (s >  1.0) s =  1.0;
    if (s < -1.0) s = -1.0;
    cmd_steering = s;
    aplicarServo(cmd_steering);
    Serial.println("OK");
  }
  else if (cmd == "STOP") {
    cmd_velocity = 0.0;
    cmd_steering = 0.0;
    aplicarMotor(0.0);
    aplicarServo(0.0);
    Serial.println("OK,STOP");
  }
  else {
    Serial.print("ERR,cmd desconocido:");
    Serial.println(cmd);
  }
}

/* ============================================================
 *  APLICAR MOTOR
 *  Convierte velocidad en m/s a PWM y configura dirección.
 *  VNH5019:
 *    INA=HIGH, INB=LOW  → atrás (en nuestro cableado)
 *    INA=LOW,  INB=HIGH → adelante (en nuestro cableado)
 *    INA=LOW,  INB=LOW  → freno (coast)
 * ============================================================ */
void aplicarMotor(float velocity_ms) {
  if (abs(velocity_ms) < 0.01) {
    // Velocidad ~0: detener motor
    digitalWrite(PIN_MOTOR_INA, LOW);
    digitalWrite(PIN_MOTOR_INB, LOW);
    analogWrite(PIN_MOTOR_PWM, 0);
    return;
  }

  // Determinar dirección (signos invertidos respecto al diagrama
  // estándar del VNH5019 para que velocidad positiva = adelante)
  if (velocity_ms > 0) {
    digitalWrite(PIN_MOTOR_INA, LOW);
    digitalWrite(PIN_MOTOR_INB, HIGH);
  } else {
    digitalWrite(PIN_MOTOR_INA, HIGH);
    digitalWrite(PIN_MOTOR_INB, LOW);
  }

  // Convertir magnitud a PWM
  int pwm_value = (int)(abs(velocity_ms) * MS_TO_PWM);
  if (pwm_value > PWM_RESOLUTION) pwm_value = PWM_RESOLUTION;
  analogWrite(PIN_MOTOR_PWM, pwm_value);
}

/* ============================================================
 *  APLICAR SERVO
 *  Convierte steering de [-1, +1] a ángulo del servo.
 *  Convención: +1 = giro derecha, -1 = izquierda
 *  Se aplica un signo negativo para invertir la convención
 *  del montaje físico actual del servo (queda al revés).
 * ============================================================ */
void aplicarServo(float steering) {
  int angle = SERVO_CENTER_DEG - (int)(steering * SERVO_HALF_RANGE);
  if (angle < SERVO_MIN_DEG) angle = SERVO_MIN_DEG;
  if (angle > SERVO_MAX_DEG) angle = SERVO_MAX_DEG;
  servo.write(angle);
}

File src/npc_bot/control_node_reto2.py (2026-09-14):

#!/usr/bin/env python3
# ============================================================================
#  control_node_reto2.py  -  Equipo NPC, WRO 2026 Future Engineers (Reto 2)
# ----------------------------------------------------------------------------
#  Control del Obstacle Challenge. Adaptado de control_node.py (Reto 1):
#    - Maquina de estados, conversion LiDAR, helpers, captura de
#      rumbo por boton, mediana_sector, publicacion de comandos.
#    - Cambia la navegacion por heading/wall/esquina  ->  Siguiendo_Camino
#      (Ruta Proyectada + recorte por color + SpiderSense).
#    - SE AÑADE: suscripcion /pilares, fusion camara-LiDAR, yaw acumulado para
#      conteo de vueltas, fin de carrera hibrido (yaw>1080 + magenta).
#
# ============================================================================

import math
import time

import numpy as np

import rclpy
from rclpy.node import Node

from std_msgs.msg import Float32, Empty, String
from sensor_msgs.msg import LaserScan
from npc_interfaces.msg import NpcPose

# ============================================================
# PARAMETROS
# ============================================================

LOOP_FREQUENCY_HZ = 40.0
LOOP_PERIOD_S = 1.0 / LOOP_FREQUENCY_HZ

# --- Velocidades (m/s) ---
VELOCIDAD_RECTA = 0.3
VELOCIDAD_CURVA = 0.25
VELOCIDAD_APROXIMACION_FIN = 0.28
VELOCIDAD_RETROCESO = -0.2

# --- LiDAR ---
LIDAR_RANGO_MIN = 0.01
LIDAR_RANGO_MAX = 3.0
LIDAR_FRENTE_DEG = 270.0
FOV_MIN_LIDAR = 185.0
FOV_MAX_LIDAR = 355.0

# --- Siguiendo_Camino: Ruta Proyectada (Capa 1) ---
MED_POR_GRADO = 6.0
CAST_R        = 0.075
VENTANA_DEG   = 25.0
PREC          = int(VENTANA_DEG * MED_POR_GRADO)   # 150
SKIP2         = 2
ABANICO_DEG   = 60.0       # tope fisico: ninguna candidata fuera de +/-60
# Ancho de la ventana permitida A PARTIR del pilar cuando hay recorte por color.
# Rojo: ventana = [ang_pilar, ang_pilar + ANCHO]. Verde: [ang_pilar - ANCHO,
# ang_pilar]. Siempre acotada por ABANICO_DEG. Estrecharla limita cuanto puede
# alejarse del pilar durante la evasion (evita irse a la esquina opuesta).
ANCHO_ABANICO_PILAR = 60.0
PASO_DEG      = 2.0
PESO_RUMBO    = 0.0015     # peso del desvio del rumbo en el scoring
DIST_SAT_SCORING = 1.6     # m: profundidad se satura aqui para el scoring.
                           # Direcciones con >=1.6m libres puntuan igual en
                           # profundidad; el rumbo desempata entre ellas (evita
                           # obsesion con el hueco mas profundo / irse al borde).

# --- SpiderSense (Capa 3) ---
SPIDER_DIST    = 0.22
SPIDER_ANG_MIN = 25.0
SPIDER_ANG_MAX = 75.0
SPIDER_DIV     = 3.0

# --- Fusion camara (Etapa 4, simplificada) ---
FOV_H_CAM      = 88.0
ANCHO_IMG      = 640
CENTRO_X       = 320
ALT_MIN_EVASION = 25
ALT_MIN_FIN     = 60

# --- Conversion angulo elegido -> servo ---
SERVO_MAX = 1.0
# Referencia FIJA del mapeo a servo, INDEPENDIENTE de ABANICO_DEG. Asi se puede
# explorar el abanico (60, 70, 75...) sin que cambie la agresividad del giro:
# un angulo de +45 produce el mismo servo siempre. Angulos por encima de esta
# referencia saturan en 1.0 (el clamp los recorta), que es lo deseado.
ABANICO_SERVO_DEG = 60.0
# Mapeo no lineal angulo->servo: servo = signo*(|ang|/ABANICO_SERVO_DEG)^K_SERVO
# K_SERVO < 1 hace el giro MAS agresivo en la zona media (ej. 35 grados da
# mas servo que el lineal), sin salto brusco. K_SERVO=1.0 seria lineal.
# Ajustar en pista: mas bajo = mas agresivo; mas alto = mas suave.
K_SERVO = 0.8

# --- Latch de evasion: al perder de vista el pilar (se acerca y sale del FoV
#     de la camara), mantener el recorte con el ultimo color/angulo vistos
#     durante este tiempo, para no resetear al abanico libre a media evasion
#     (evita irse a la esquina opuesta). Se cancela si aparece un pilar nuevo.
LATCH_EVASION_S = 0.6

# --- Conteo de vueltas y fin de carrera ---
YAW_3_VUELTAS_DEG = 1080.0     # 3 vueltas (referencia)
YAW_FIN_UMBRAL_DEG = 990.0     # llave de seguridad para el fin de carrera
# Parada por distancia frontal (como Reto 1)
SECTOR_FRONTAL = (-5.0, 5.0)
UMBRAL_INICIO_FRENADO = 2.0
DIST_OBJETIVO_MIN = 1.2
DIST_OBJETIVO_MAX = 1.5
TIEMPO_CONFIRMACION_PARADA_S = 0.2


# ============================================================
# CLASE PRINCIPAL
# ============================================================

class ControlNodeReto2(Node):

    def __init__(self):
        super().__init__('control_node_reto2')

        # --- Estado de sensores ---
        self.lidar = None
        self.lidar_ranges_np = None
        self.pose = None
        self.start_received = False

        # --- Estado de navegacion ---
        self.estado = 'BOOT'
        self.section_angle = 0.0       # rumbo objetivo absoluto (theta normalizado)
        self.cmd_velocity = 0.0
        self.cmd_steering = 0.0

        # --- Yaw acumulado (conteo de vueltas) ---
        self.yaw_acumulado = 0.0       # grados, des-normalizado
        self.theta_anterior = None     # para detectar saltos de +pi/-pi

        # --- Camara / fusion ---
        self.pilares_str = ""          # ultimo String de /pilares

        # --- Fin de carrera ---
        self.tiempo_inicio_banda_parada = None

        # --- Latch de evasion (recordar el ultimo pilar tras perderlo) ---
        self.latch_color = None        # 'R'/'G' del ultimo pilar visto
        self.latch_ang = 0.0           # su ultimo angulo visto
        self.latch_t = None            # instante (time.time) del ultimo avistaje

        # --- Diagnostico ---
        self._diag_contador = 0

        # --- Publicadores / Suscriptores ---
        self.pub_motor = self.create_publisher(Float32, '/cmd_motor', 10)
        self.pub_servo = self.create_publisher(Float32, '/cmd_servo', 10)

        self.create_subscription(LaserScan, '/scan', self._callback_lidar, 10)
        self.create_subscription(NpcPose, '/npcpos', self._callback_pose, 10)
        self.create_subscription(Empty, '/start', self._callback_start, 10)
        self.create_subscription(String, '/pilares', self._callback_pilares, 10)

        self.create_timer(LOOP_PERIOD_S, self.main_loop)
        self.get_logger().info('control_node_reto2 iniciado. Esperando datos...')

    # ==========================================================
    # CALLBACKS
    # ==========================================================

    def _callback_lidar(self, msg: LaserScan):
        self.lidar = msg
        ranges = np.array(msg.ranges)
        ranges[(ranges < LIDAR_RANGO_MIN) | (ranges > LIDAR_RANGO_MAX)] = np.nan
        # Rellenar nan SOLO dentro del FoV util (193-350 lidar). Un nan ahi es
        # ruido (deberia haber medida), asi que se sustituye por el vecino
        # valido mas cercano para que el marching no lo lea como "libre".
        # Fuera del FoV (chasis bloquea) se deja nan -> tratado como RANGO_MAX.
        self.lidar_ranges_np = self._rellenar_nan_en_fov(ranges, msg)
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

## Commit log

2026-05-22 primer commit
    En este commit lo que hicimos fue crear la carpeta de v-photos
2026-05-22 photos de las planificaciones en carton
2026-06-03 upload of the stl files
    [25d-metal-gearmotor-34-47-encoder.step, Canal 2 Cables Tapa.3mf, Canal 2 Cables Tapa.stl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]
2026-06-03 Crear la carpeta de fotos del equipo
2026-06-05 Create primer reto, caja más grande que el otro.md
2026-06-09 Update README.md
    Cambios en algunos formatos de los cuadros, asi como de fotos para hacer mas entendible las explicaciones
2026-06-09 Update README.md
    Ajustes en el Indice que no mostraba sección 6
2026-06-23 Update Formatos y Fotos README.md
    Se ajustaron formato de fotos para reducir el espacio que ocupan y ademas se incluyeron fotos con ubicació de sensores y chasis.
    Correciones menores en texto
2026-06-24 Inclusión de Apartado 7
    Se incluyó el apartado 7 de Pensamiento Sistémico y Decisiones de Ingenieria Criterio 4
2026-06-27 Se incorporó Sección 6 del Reto de Obstáculos
2026-06-28 Incorporación de Fotos de Sensores y Distribución de Potencia
2026-06-29 Inclusión de Estructura de Código
2026-06-30 Update Piezas 3D.md
    Inclusión de Anexo 8.1
2026-07-02 Fotos de Ensamblaje
2026-07-03 Notas de Ensamblaje
2026-07-08 Actualización de Metricas de Desempeño, Fotos y Justificativo de Elección de RO2
2026-07-08 Cambio de Foto Final
2026-07-09 Poner todos los links de los videos del reto 1
2026-09-10 Actualizado con Ajustes de Recomendaciones de Regional de Valencia.md
    Se ajustó explicación de las secciones 4 y 5 con mas detalle de las piezas de movilidad con mas detalle de su evolución. Tambien se incluyó mas explicación de la Topología de Comunicación y de los ca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
2026-09-15 Add files via upload
    Se añade el Journal o Diario de trabajo durante estos 7 meses de trabajo, que explica la bitacora de los pasos que seguimos para la contrucción y programación de Proyecto Mahoraga
